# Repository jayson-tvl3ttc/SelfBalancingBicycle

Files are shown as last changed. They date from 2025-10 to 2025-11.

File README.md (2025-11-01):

#  Self-Balancing Bicycle Platform  
**Hardware and Control System Design Based on STM32 and FreeRTOS**  

---

##  Overview

This project presents a **two-wheeled self-balancing bicycle platform** that integrates **embedded hardware design**, **real-time control algorithms**, and **upper-computer visualization software**.  
The system utilizes **an STM32 microcontroller**, **MPU6050 IMU sensor**, and **dual motor control** with a **momentum wheel and steering servo**, achieving balance through **cascaded PID control** and **FreeRTOS task scheduling**.

The platform is designed for research and educational purposes, demonstrating practical implementation of control theory, sensor fusion, and embedded systems in robotics.



---

##  System Features

-  **Cascaded PID Control**  
  Combines angular velocity and angle feedback for stable balance control.

-  **Quaternion-Based Attitude Estimation**  
  Uses complementary filtering and MPU6050 data fusion to determine pitch and roll.

-  **FreeRTOS Task Management**  
  Multitasking structure for sensor acquisition, control loop, and communication threads.

-  **Bluetooth Communication**  
  Supports remote parameter tuning, data transmission, and control commands.

-  **Upper-Computer Visualization**  
  Python-based GUI for real-time data plotting, PID tuning, and system monitoring.

-  **Compact Hardware Platform**  
  Custom PCB with integrated STM32F103C8T6, voltage regulator circuit, bluetooth module,and OLED display.

---

##  System Architecture

值 (2)

---

## Hardware Design

The **Self-Balancing Bicycle Platform** was developed as a compact embedded system integrating sensing, computation, and control.  
It is based on an **STM32F103C8T6** microcontroller and incorporates multiple modules to achieve real-time dynamic balance and steering stabilization.

| Component | Description |
|---|---|
| **Microcontroller** | STM32F103C8T6 (Cortex-M3, 72 MHz, 64 KB Flash) |
| **IMU Sensor** | MPU6050, combining a 3-axis accelerometer and a 3-axis gyroscope |
| **Actuators** | EA90 three-phase brushless motors for drive and balance control , and a servo motor for steering |
| **Display** | 0.96" OLED (I²C interface) showing pitch angle, PWM output, and status |
| **Communication** | JDY-31 Bluetooth module for remote data monitoring and parameter adjustment |
| **Power Supply** | 7.4V lithium-ion battery with AMS1117 voltage regulation |
| **PCB Design** | Custom two-layer PCB designed in **Altium Designer** |

---

### Hardware Implementation Highlights

- The STM32 microcontroller handles all real-time tasks under the FreeRTOS environment.  
- The MPU6050 provides raw motion data for attitude estimation.  
- A momentum wheel generates compensating torque to maintain upright balance.  
- The servo motor adjusts steering for horizontal stabilization.  
- The PCB layout minimizes interference between power and signal lines using a ground plane and separated analog/digital regions.  
- All modules were validated through bench testing before system integration.

值



*Custom two-layer PCB for the control system.*

---

##  Control Algorithm

The control system applies a **cascaded PID controller** that stabilizes both angular position and angular velocity of the bicycle.  
A quaternion-based complementary filter processes the IMU data to obtain accurate pitch and roll angles.

### Algorithm Overview

- The **outer PID loop** regulates the tilt angle (pitch) to maintain balance.  
  It outputs a desired angular velocity for the inner loop.  
- The **inner PID loop** stabilizes angular velocity by adjusting motor torque through PWM control.  
- Both loops run in real time under **FreeRTOS** tasks with a 2 ms sampling period.  
- Attitude estimation is derived from **gyro and accelerometer fusion**, where 98% weight is assigned to the gyroscope to minimize noise and drift.

值 (1)

### PID Tuning and Parameters

Parameters were experimentally tuned to balance stability and responsiveness.  
Step response analysis was used to refine each loop’s gain values.

| Loop | Kp | Ki | Kd | Sampling Time |
|---|----|----|----|---|
| **Outer (Angle)** | 90 | 0.5 | 3 | 2 ms |
| **Inner (Velocity)** | 25 | 1.2 | 0.1 | 2 ms |

The final configuration achieved fast convergence with minimal overshoot.  
Under disturbance tests, the bicycle restored its balance within 0.3 seconds after small perturbations.

---

##  Experimental Results

### Performance Evaluation
- The platform maintained stable balance with **±3° maximum pitch deviation**.  
- The response time to external disturbances was **less than 300 ms**.  
- Angular drift was effectively suppressed through quaternion fusion.  
- The system demonstrated consistent stability during extended operation (>30 minutes).  

### Observations
- The complementary filter provided smoother attitude estimation compared to raw gyroscope data.  
- The cascaded PID structure improved dynamic response over single-loop control.  
- Thermal effects on sensor bias were mitigated through initial calibration at power-up.



*Prototype of the self-balancing bicycle during testing.*


*Self-balancing bicycle control system platform.*


*Momentum wheel module.*


*Rear wheel drive module.*

---
##  Author

**Jayson Chen**  
Master’s in Audio and Music Technology  
University of York  

Contact: *[jaysonchen816@gmail.com]*

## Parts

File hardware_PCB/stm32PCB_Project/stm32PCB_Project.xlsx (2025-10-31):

Comment | Description | Designator | Footprint | LibRef | Quantity
100uF/63V | 贴片电解电容 | C1 | SMD-EC8X8X10 | SMD_ECAP | 1
0.01uF | 无极性电容 | C2, C3 | 0603C | CAP_1 | 2
220uF/35V | 贴片电解电容 | C4 | SMD-EC8X8X10 | SMD_ECAP | 1
0.1uF | 无极性电容 | C5 | 0603C | CAP_1 | 1
IN5824 | 肖特基二极管 | D1 | SMA/DO-214AC | DIODE SCHOTTKY | 1
GREEN | 发光二极管 | D2, D3, D4, D5 | 0805_LED_S1 | 0805 翠绿 | 4
HOLE | 固定孔 | H1, H2, H3, H4 | LQ_SCROW3&5MM | HOLE | 4
Female HDR1X6 | 蓝牙模块 | J1 | Fe-HDR1X6/2.54-S | Female HDR1X6 | 1 | norm = invSqrt(ax*ax + ay*ay + az*az);ax = ax * norm;ay = ay * norm;az = az * norm;
Pin HDR1X3 | 舵机模块 | J2 | Pin HDR1X3/2.54mm-W | Pin HDR1X3 | 1
Female HDR1X4 | OLED显示屏模块 | J3 | Fe-HDR1X4/2.54-S | Female HDR1X4 | 1 | 引脚 | 功能
Female HDR1X8 | MPU6050模块 | J4 | Fe-HDR1X8/2.54-S | Female HDR1X8 | 1 | PB12，PB13 | OLED屏幕通信 | norm = invSqrt(ax*ax + ay*ay + az*az);
Pin HDR1X4 | 串口模块 | J5 | Pin HDR1X4/2.54mm-W | Pin HDR1X4 | 1 | PB6，PB7，PB8 | PWM脉冲信号输出 | ax = ax * norm;
Encoder_XY | 正交编码器 | J6 | Pin HDR2X3/2.54mm-S | Encoder_XY | 1 | PA9，PA10 | 上位机串口通信 | ay = ay * norm;
Pin HDR1X6 | 电机控制模块 | J7, J8 | Pin HDR1X6/2.54mm-W | Pin HDR1X6 | 2 | PB6，PB7 | 姿态传感器I2C通信 | az = az * norm;
33uH | 贴片电感 | L1 | CD75 | INDUCTOR | 1 | PB8，PB9 | 预留方向控制推挽输出
330Ω | 贴片电阻 | R1 | 0603_R | 0603 330Ω (3300) 1% | 1 | PA4 | ADC模拟信号采集
4K7Ω | 贴片电阻 | R2 | 0603_R | 0603 330Ω (3300) 1% | 1 | PA2，PA3 | 蓝牙串口通信
3K3Ω | 贴片电阻 | R3 | 0603_R | 0603 330Ω (3300) 1% | 1 | PA1，PA0 | 编码器脉冲计数输入
47KΩ | 贴片电阻 | R4, R5 | 0603_R | 0603 330Ω (3300) 1% | 2 | PC13 | LED闪烁控制
1kΩ | 贴片电阻 | R6 | 0603_R | 0603 330Ω (3300) 1% | 1
SS-12F23 | 开关 | S1 | SS-12F23 | SS-12F23 | 1
POWER | 电源插座 | U1 | KF301-5.0-2P | 电源焊点 | 1
STM32F103C8T6 MODULE | STM32最小系统板 | U2 | STM32F103C8T6 MODULE | STM32F103C8T6 MODULE | 1
LM2596-5.0 | DC降压芯片 | U3 | TO263-5A | LM2596-5.0 | 1
10K | 可调电阻器 | VR1 | 3296W | RESVR | 1
vx = Mat.DCM_T[0][2];vy = Mat.DCM_T[1][2];vz = Mat.DCM_T[2][2];

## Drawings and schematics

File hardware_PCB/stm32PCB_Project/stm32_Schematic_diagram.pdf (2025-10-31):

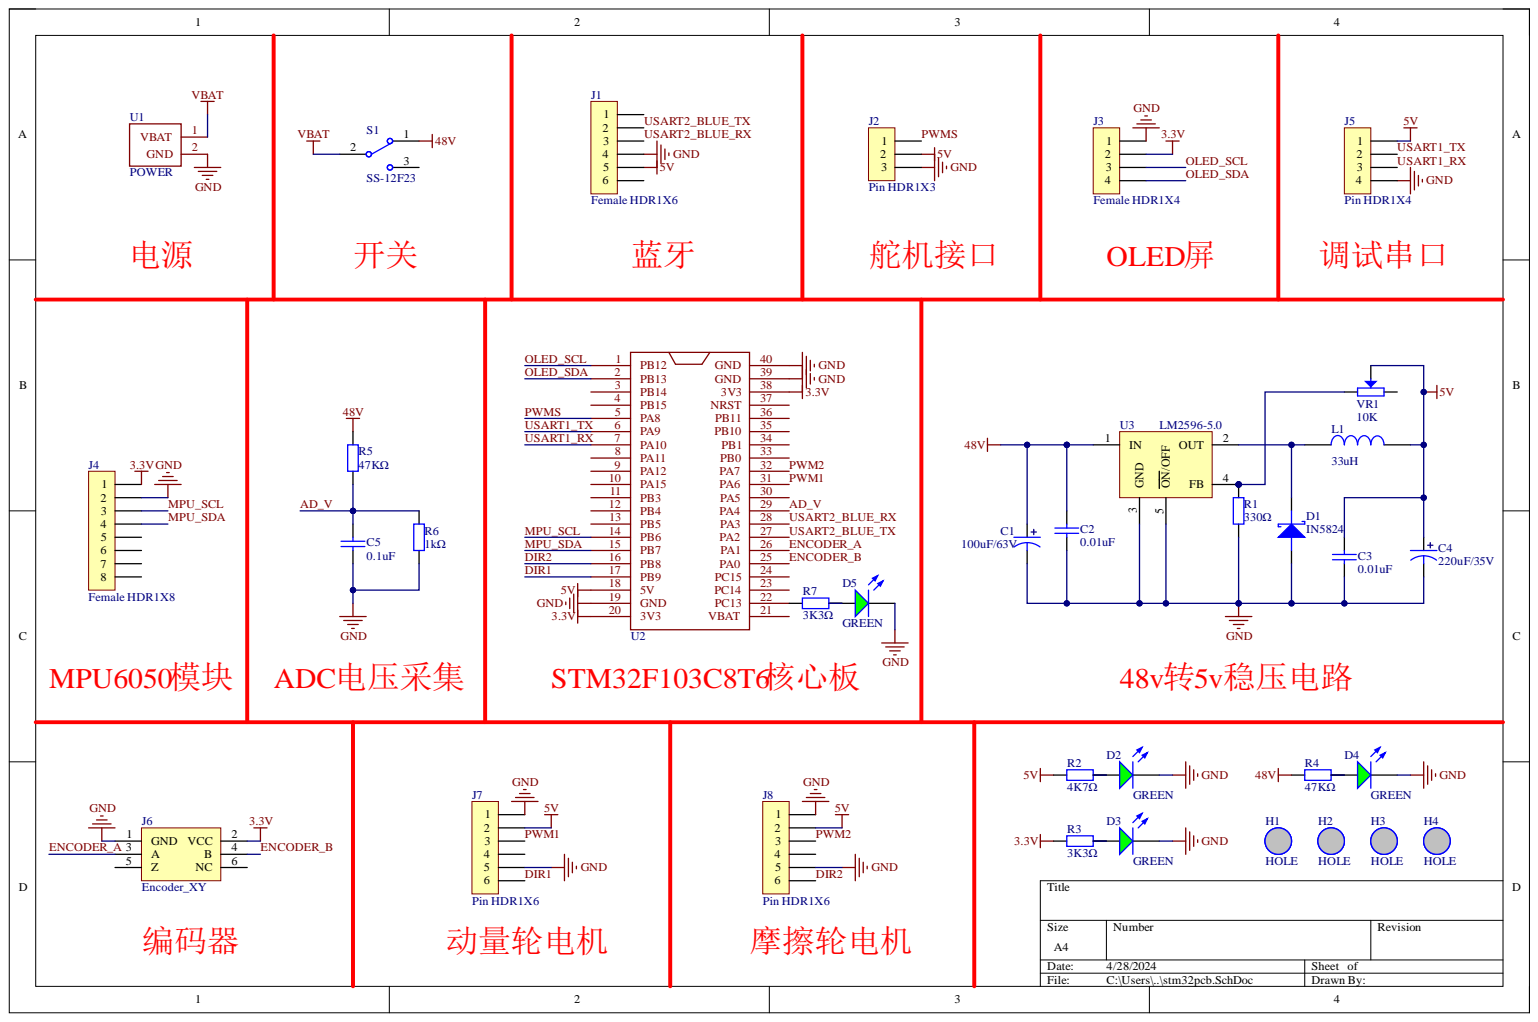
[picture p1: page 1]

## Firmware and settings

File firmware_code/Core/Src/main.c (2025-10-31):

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
/* Includes ------------------------------------------------------------------*/
#include "main.h"
#include "cmsis_os.h"
#include "adc.h"
#include "dma.h"
#include "i2c.h"
#include "tim.h"
#include "usart.h"
#include "gpio.h"

/* USER CODE BEGIN Includes */
#include "mpu6050.h"
#include "stdio.h"
#include "oled.h"
#include "display.h"
#include "pid.h"
#include "controller.h"
#include "soft_iic.h"
#include "led.h"
/* USER CODE END Includes */


void SystemClock_Config(void);
void MX_FREERTOS_Init(void);
/**
  * @brief  The application entry point.
  * @retval int
  */
int main(void)
{
  /* MCU Configuration--------------------------------------------------------*/

  /* Reset of all peripherals, Initializes the Flash interface and the Systick. */
  HAL_Init();

  /* Configure the system clock */
  SystemClock_Config();

  /* Initialize all configured peripherals */
  MX_GPIO_Init();
  MX_DMA_Init();
  MX_ADC1_Init();
  MX_USART1_UART_Init();
  MX_USART2_UART_Init();
//  MX_I2C1_Init();
  MX_TIM3_Init();   //PWM1,PWM2
  MX_TIM2_Init();   //ENCODER
  MX_TIM1_Init();   //PWMS
  
  /* USER CODE BEGIN 2 */
  HAL_TIM_PWM_Start(&htim3,TIM_CHANNEL_1 );             //开启定时器3的通道1的PWM  动量平衡使用
  HAL_TIM_PWM_Start(&htim3,TIM_CHANNEL_2 );             //开启定时器3的通道2的PWM  前进后退使用
  HAL_TIM_PWM_Start(&htim1,TIM_CHANNEL_1 );             //开启定时器1的通道1的PWM  舵机转向控制使用
  
  soft_iic_init();                                      //IIC端口初始化
  mpu6050_init();                                       //MPU6050初始化
  
  /* mpu6050模块在位检测 BEGIN */
  led_set(RUN_LED,100, 50,0);
  while(1)
  {
    if(MPU6050ReadID() != 1)
    {
      led_operation(&run_led);
      HAL_Delay(1);
      printf("没有检测到MPU6050传感器！\r\n");
    }
    else
      break;
  }
  /* mpu6050模块在位检测 END */
  
  get_iir_factor(&Mpu.att_acc_factor,0.005f,25);   	    //姿态解算时加速度低通系数 
  
  readCalData();                                        //上电开机读取一次写入到内存里面的陀螺仪校准数据
  DISplay_Init();			                                  //初始化OLED  
  DISplay_Clear();                                      //OLED清屏
  all_pid_init();                                       //pid参数初始化
  mainMotorEN();                                        //飞轮电机使能
  EnableAuxMotor();                                     //前进后退电机使能
//  __HAL_TIM_SetCompare(&htim3, TIM_CHANNEL_1, 1150);
//	osDelay(100);
  /* USER CODE END 2 */

  /* Call init function for freertos objects (in freertos.c) */
  MX_FREERTOS_Init();
  /* Start scheduler */
  osKernelStart();

  /* We should never get here as control is now taken by the scheduler */
  /* Infinite loop */
  /* USER CODE BEGIN WHILE */
  while (1)
  {
    /* USER CODE END WHILE */

    /* USER CODE BEGIN 3 */
  }
  /* USER CODE END 3 */
}

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
/**
  * @brief  Period elapsed callback in non blocking mode
  * @note   This function is called  when TIM4 interrupt took place, inside
  * HAL_TIM_IRQHandler(). It makes a direct call to HAL_IncTick() to increment
  * a global variable "uwTick" used as application time base.
  * @param  htim : TIM handle
  * @retval None
  */
void HAL_TIM_PeriodElapsedCallback(TIM_HandleTypeDef *htim)
{
  if (htim->Instance == TIM4) {
    HAL_IncTick();
  }
}

/**
  * @brief  This function is executed in case of error occurrence.
  * @retval None
  */
void Error_Handler(void)
{
  /* USER CODE BEGIN Error_Handler_Debug */
  /* User can add his own implementation to report the HAL error return state */
  __disable_irq();
  while (1)
  {
  }
  /* USER CODE END Error_Handler_Debug */
}

#ifdef  USE_FULL_ASSERT
/**
  * @brief  Reports the name of the source file and the source line number
  *         where the assert_param error has occurred.
  * @param  file: pointer to the source file name
  * @param  line: assert_param error line source number
  * @retval None
  */
void assert_failed(uint8_t *file, uint32_t line)
{
  /* USER CODE BEGIN 6 */
  /* User can add his own implementation to report the file name and line number,
     ex: printf("Wrong parameters value: file %s on line %d\r\n", file, line) */
  /* USER CODE END 6 */
}
#endif /* USE_FULL_ASSERT */

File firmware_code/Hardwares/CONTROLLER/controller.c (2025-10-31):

#include "controller.h"
#include "imu.h"
#include "pid.h"
#include "encoder.h"
#include "mpu6050.h"
#include "imath.h"
#include "tim.h"
#include "bluetooth.h"
_OUT_Motor Motor1 = {0};
_OUT_Motor Motor2 = {0};


//static uint16_t pwmspeed;
static float Mid = 1.7;                                  //机械中值   占空比中值42.5-42.7
float Vertical_Kp=860;   //1000   2050                              //直立环kp（正）
float Vertical_Kd=3;			//30															//直立环kd（正）
int pwm_out1;																							//直立环输出 负反馈
float Velocity_Kp=-0.07;	//-0.375																		//速度环kp（负）
float Velocity_Ki=-0.0;																			//速度环ki（负）  ki值大约为kp值的200分之一
int pwm_out2;																							//速度环输出 正反馈



/**
  * @brief   外环速度控制器
  */
static void vel_controller(void)                                       
{                            
  all.vel_encoder.expect = 0.0f;                              //外环角度期望角度给0
  all.vel_encoder.feedback = encoderINFO.mainNumberValue;    //编码器速度值作为反馈量   此处根据实际情况进行正负选择 +
	
  pid_controller(&all.vel_encoder);                           //外环pid控制器  
}
/**
  * @brief   内环角度控制器
  */
static void angle_controller(void)                                     
{
  all.rol_angle.expect = all.vel_encoder.out;                 //外环输出作为内环期望值
	//all.rol_angle.expect = -2.5f;                 //外环输出作为内环期望值
  all.rol_angle.feedback = (-att.rol)+(0);                    //姿态解算的rol角作为反馈量
  pid_controller(&all.rol_angle);                             //内环pid控制器      
}
/**
  * @brief   内环角速度控制器
  */
static void gyro_controller(void)                                      
{                            
  all.rol_gyro.expect = all.rol_angle.out;                    //外环输出作为内环期望值
	//all.rol_gyro.expect = -0.0f;                    //外环输出作为内环期望值
  all.rol_gyro.feedback = -(Mpu.deg_s.y);                       //角速度值作为反馈量
  pid_controller(&all.rol_gyro);                              //内环pid控制器  
}
/**
  * @brief   三环串级PID控制器运行
  */
void _controller_perform(void)                                  
{   
  vel_controller();                                           //速度控制器
  angle_controller();                                         //角度控制器
  gyro_controller();                                          //角速度控制器    
}

/**
  * @brief    直立环PD
使用车身倾斜角度和机械角度零点以及倾斜速度这三个数据，
车身倾斜角度与机械角度零点之差作为比例项，车身倾斜角度与机械角度零点之差的累加作为积分项，车身倾斜速度作为微分项。
  */

int Vertical(float Mid, float angle, float gyro)
{
  int pwmout1;
	pwmout1 = Vertical_Kp*(angle-Mid)+Vertical_Kd*gyro;
  return pwmout1; 
}

/**
  * @brief   速度环PI

  */

int Velocity(int Encoder_motor)
{
  static int Encoder_s,Encoder_Err_Lowout_Last,pwmout2,Encoder_Err,Encoder_Err_Lowout;
	float a=0.7;
	//计算速度偏差
	Encoder_Err = Encoder_motor;
	//对速度偏差进行低通滤波
	Encoder_Err_Lowout=(1-a)*Encoder_Err+a*Encoder_Err_Lowout_Last;	
	Encoder_Err_Lowout_Last=Encoder_Err_Lowout;
	//对速度偏差积分，积分出位移
	Encoder_s+=Encoder_Err_Lowout;
	//积分限幅
	Encoder_s=Encoder_s>10000?10000:(Encoder_s<(-10000)?(-10000):Encoder_s);
	//速度环控制输出计算
	pwmout2=Velocity_Kp*Encoder_Err_Lowout+Velocity_Ki*Encoder_s;
	return pwmout2;
	
}


/**
  * @brief   检测小车是否倒下
  * @param   inAngleData 输入的参考角度值
  * @retval  detectionMark 返回是否倒下标志 1：倒下 0：正常
  */
static uint8_t detectionFallDown(float inAngleData)
{
  uint8_t detectionMark = 0;

  if( f_abs(inAngleData) > 20.0f )                                             
  {
    detectionMark = 1;                                              //关闭输出标志置位                 
  }                                                            
  return detectionMark;     
}
/**
  * @brief   PWM输出
  * @param   pwm1 输入第一路pwm
  * @param   pwm2 输入第二路pwm     20v->1650
  * @retval  x
  */
uint16_t pwm3=1144;
static void pwmMotorOut(uint16_t pwm1 , uint16_t pwm2 )
{
  __HAL_TIM_SetCompare(&htim3, TIM_CHANNEL_1, u16RangeLimit(pwm1 , 0 , 2000));	          //控制占空比
  __HAL_TIM_SetCompare(&htim3, TIM_CHANNEL_2, u16RangeLimit(pwm2 , 0 , 2000));
	//__HAL_TIM_SetCompare(&htim3, TIM_CHANNEL_2, u16RangeLimit(pwm3 , 0 , 2000));					//50hz 18000 启动17225 
																																												//500hz 1800 启动1355 占空比24
																																												//100hz 9000 启动6797 占空比24
}

/**
  * @brief   控制器输出
  */
 uint16_t motor_speed; 

void _controller_output(void)                                    
{
  static uint8_t FalldownAndRestart = 0;
	
  
  /* 检测是否倒下 */
  if( detectionFallDown(att.rol)==1 )                 
  {
    motor_speed = 2000;                                 //后轮电机速度设为最小
    FalldownAndRestart = 1;                                 //倒下之后需复位重启将其清除才能正常进入到平衡状态
    DisableAuxMotor();                                      //失能关闭前后动力电机
    Motor1.out = 0;                                         //清除电机PWM输出值           
    Motor2.out = 0;                                         //清除电机PWM输出值    
    pwm_out1 = 0;
		pwm_out2 = 0;
    clear_integral(&all.vel_encoder);                       //清除积分        
    clear_integral(&all.rol_angle);                         //清除积分                
    clear_integral(&all.rol_gyro);                          //清除积分
		
  }                                                                   
  else if( (acc_raw.z >= 2500 && acc_raw.z <= 5000) && f_abs(att.rol) <= 20.0f && FalldownAndRestart == 0)                                                               
  {
    //N20_motor_speed = 1500;
		
    EnableAuxMotor();                                       //使能前后动力电机
    
		Motor1.out =  all.rol_gyro.out;                         //正常输出    
		
  }
  /* 根据输出正负来判断方向 */
//  if(Motor1.out>0)  dirAnticlockwise();   
//  else  dirClockwise();
	//pwm_out1=Vertical(Mid,att.rol,Mpu.deg_s.y+1.1);
	//pwm_out2=Velocity(encoderINFO.mainNumberValue);
	
//	if(pwm_out1+pwm_out2>0)  dirAnticlockwise();              //预留方向控制输出
//  else  dirClockwise();
// 
  TurnLeftOrRight(BluetoothParseMsg.Xrocker);               //左右转向控制
  goForwardOrBackward(BluetoothParseMsg.Yrocker);           //前后方向控制

	

  //pwmMotorOut( pwm_out1+pwm_out2+1150 , motor_speed);                 //串级pid电机输出
	//pwmMotorOut( pwm_out1+1150 , motor_speed);                          //并级pid电机输出
	
	
	pwmMotorOut( Motor1.out+1150 , motor_speed);                 //电机输出
	//pwmMotorOut( int_abs(Motor1.out) , motor_speed);                 //电机输出

	
}
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

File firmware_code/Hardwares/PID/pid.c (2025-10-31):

#include "pid.h"



_ALL_PID all;

/**
  * @brief   存储pid控制器参数 三行五列，每行代表一个pid控制器参数，每列对应参数 0.kp 1.ki 2.kd 3.积分限幅  4.pid输出限幅值
  * @param   x
  * @retval  x
  */
/*//机械中值-5.8
角速度环

角度环
在调试过程中，角度环主要是用来补偿速度环带来的溢出或者延迟，因此角度环我只采用了简单的位置式P进行处理，并且调试过程中是粗调的。

速度环
速度环虽然作为最外环，我却认为是很重要的一环，因为他决定了你单车受到干扰后保持稳定的能力，采用的是位置式PID进行精调。
很简单的例子，假设单车往左倒需要动轮逆时针转动（车屁股视角），通过编码器的极性你就可以判断出此时车身的姿态到底是往哪边倒的，
此时为了让车往右的方向归，便需要不断加速来平衡，这中间就涉及到了溢出的问题，
也就是车子会向右倒，这时候就需要粗调角度环来抑制这个影响。（当车身右倒，角度环大就抵消了）

调试方法
先精调角速度环，到往一个方向倒开始觉得困难了就可以调速度环，加上了速度环以后，车子能立2s左右倒下后开始调速度环，
一开始建议大家三个环都只进行普通的P控制，实测效果也非常好，能立且抗干扰能力比Lqr好太多。
调参过程中尽可能大的增加速度环，外界干扰姿态，观察归正情况，若有过冲则增大角度环，而角速度环更像是一个比例系数（如果是纯P），
所有的修正均可通过修正速度环处理，调好以后加上D值精调。*/

const float  controller_parameter[3][5] =
{
  /* 0.kp 1.ki 2.kd 3.积分限幅  4.pid输出限幅值 */
//    {7.3 , 0.0,  0,  550 , 2000 },                           //rol_angle     内环角度环    小车面包板   
//    {0.070 , 0.00005,  0.055,  500 , 2000 },                 //vel_encoder   外环速度环       
//    {26.5 ,  0.0,  0,  500 , 2000 },                         //gyro          内环角速度环 
		
//    {7.5 , 0.0,  0,  550 , 2000 },                           //rol_angle     内环角度环       小车PCB
//    {0.068 , 0.00005,  0.055,  500 , 2000 },                 //vel_encoder   外环速度环       
//    {26.5 ,  0.0,  0,  500 , 2000 },                         //gyro          内环角速度环 
		
		{4.72 , 0.0,  0,  550 , 2000 },                            //rol_angle     内环角度环       大车  （1）4.56 0.0075 11.65 （2）0.00735
    {0.007 , 0.0,  0,  550 , 2000 },                 						//vel_encoder   外环速度环     加后轮驱动 （1）4.72 0.007 12               
    {11.9 , 0.0,  0,  550 , 2000 },                            //gyro          内环角速度环 
		
};

/**
  * @brief   PID参数初始化配置
  * @param   *controller PID控制器指针，指向不同的控制器
  * @param   label PID参数标号，选择对应控制器的参数数组标号
  * @retval  x
  */
void pid_init(_PID *controller,uint8_t label)
{
    controller->kp              = controller_parameter[label][0];         
    controller->ki              = controller_parameter[label][1];         
    controller->kd              = controller_parameter[label][2];         
    controller->integral_max    = controller_parameter[label][3];         
    controller->out_max         = controller_parameter[label][4];               
}

//PID参数初始化
void all_pid_init(void)
{
    pid_init(&all.rol_angle,0);
    pid_init(&all.vel_encoder,1);
    pid_init(&all.rol_gyro,2);
} 

/**
  * @brief   PID控制器
  * @param   *controller PID控制器指针，指向不同的控制器
  * @retval  controller->out 经过控制后的输出值
  */
float pid_controller(_PID *controller)
{
    controller->err_last = controller->err;                                                  //保存上次偏差
    controller->err = controller->expect - controller->feedback;                            //偏差计算
    controller->integral += controller->ki * controller->err;                               //积分  
    //积分限幅
    if(controller->integral >  controller->integral_max)     controller->integral =  controller->integral_max;
    if(controller->integral < -controller->integral_max)     controller->integral = -controller->integral_max;
    //pid运算
    controller->out =  controller->kp*controller->err + controller->integral + controller->kd*(controller->err-controller->err_last);
   
    //输出限幅
    if(controller->out >  controller->out_max)   controller->out =  controller->out_max;
    if(controller->out < -controller->out_max)   controller->out = -controller->out_max;
    return controller->out;
}
/**
  * @brief   PID控制器积分项清除
  * @param   *controller PID控制器指针，指向不同的控制器
  * @retval  x
  */
void clear_integral(_PID *controller)
{
    controller->integral = 0.0f;
}

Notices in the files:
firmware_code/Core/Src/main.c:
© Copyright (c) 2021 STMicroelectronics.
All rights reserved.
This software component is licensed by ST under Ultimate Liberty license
